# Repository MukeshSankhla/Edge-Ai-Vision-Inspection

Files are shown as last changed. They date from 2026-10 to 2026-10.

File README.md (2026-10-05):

# Edge AI Vision Inspection System
### Automated Optical Inspection (AOI) for Battery Management System (BMS) PCB & PCBA Manufacturing

An industrial-grade, multi-stage Automated Optical Inspection (AOI) platform engineered for electronics manufacturing lines. The system automates quality control on a 6-slot indexing rotary turntable, executing real-time defect detection, assembly verification, and bare PCB surface inspection using edge-optimized AI models.

Designed for edge deployment on the **Arduino UNO Q (Qualcomm QRB2210 Linux MPU + STM32U585 Zephyr MCU)** as well as standard Linux AArch64 / x86 SBCs and Windows workstations.

> 📖 **Project Story & Step-by-Step Build Tutorial:**
> Looking for the complete build walkthrough, 3D printing guide, Edge Impulse BYOM workflow, and step-by-step setup? Read the **[Project Guide & Build Tutorial](file:///c:/Users/MAKERBRAINS/Downloads/Edge%20Ai%20Vision%20Inspection/PROJECT_GUIDE.md)**!

---

## 📑 Table of Contents

- [System Overview](#-system-overview)
- [Repository Structure](#-repository-structure)
- [End-to-End Inspection Pipeline](#-end-to-end-inspection-pipeline)
- [Deep Learning Models](#-deep-learning-models)
  - [1. Slot Occupancy Detection](#1-stage-1-slot-occupancy-detection)
  - [2. Bare PCB Defect Inspection](#2-stage-2-bare-pcb-defect-inspection)
  - [3. Big Components Inspection](#3-stage-3a-big-components-inspection)
  - [4. Small Components Inspection](#4-stage-3b-small-components-inspection)
- [Hardware Architecture & Rotary Table](#-hardware-architecture--rotary-table)
- [Production Runtime (BMS EIM Vision Inspection)](#-production-runtime-bms-eim-vision-inspection)
- [Model Training & Conversion Workflow](#-model-training--conversion-workflow)
- [Installation & Quickstart](#-installation--quickstart)
  - [Prerequisites](#prerequisites)
  - [Running on Host PC (Windows / Linux)](#running-on-host-pc-windows--linux)
  - [Running on Arduino UNO Q (Linux SBC)](#running-on-arduino-uno-q-linux-sbc)
- [Web Dashboard Features](#-web-dashboard-features)
- [License & Credits](#-license--credits)

---

## 🔭 System Overview

```
                      ┌──────────────────────────────────────────────┐
                      │             Industrial Camera / USB          │
                      └──────────────────────┬───────────────────────┘
                                             │ Video Stream (RGB)
                                             ▼
┌────────────────────────────────────────────────────────────────────────────────────────┐
│                        Edge Processing Unit (Arduino UNO Q / Host PC)                  │
│                                                                                        │
│   ┌────────────────────────────────────────────────────────────────────────────────┐   │
│   │                      Flask Web Dashboard & AOI Controller                      │   │
│   └──────┬──────────────────────────────────────────────────────────────────┬──────┘   │
│          │                                                                  │          │
│          ▼ Image Frames                                                     ▼ Commands │
│   ┌─────────────────────────────────────────┐               ┌──────────────────────┐   │
│   │   Pure Native .EIM Model Inference Engine│              │  Hardware Interface  │   │
│   │   (ARM NEON SIMD / Shared Memory IPC)   │              │  (Bridge RPC / UART) │   │
│   │                                         │              └──────────┬───────────┘   │
│   │   1. Slot Occupancy (Empty/PCB/PCBA)    │                         │               │
│   │   2. Bare PCB Defects (Scratches/Bridges│                         │               │
│   │   3. Big Components (6 Parts - 12 Cls)  │                         │               │
│   │   4. Small Passives (13 Parts - 26 Cls) │                         │               │
│   └─────────────────────────────────────────┘                         │               │
└───────────────────────────────────────────────────────────────────────┼────────────────┘
                                                                        │
                                   ┌────────────────────────────────────┴────────────────┐
                                   │ STM32U585 MCU / Arduino Microcontroller Firmware    │
                                   └──────────────┬──────────────────────────┬───────────┘
                                                  │ PWM Pulse Stream         │ Single-Wire Data
                                                  ▼                          ▼
                                      ┌──────────────────────┐   ┌──────────────────────┐
                                      │ 6-Slot Rotary Table  │   │ WS2812B NeoPixel LED │
                                      │   (Servo Actuator)   │   │  (PASS/FAIL/STATUS)  │
                                      └──────────────────────┘   └──────────────────────┘
```

The system inspects printed circuit boards at each step of the manufacturing lifecycle:
1. **Verifies fixture occupancy** before initiating camera capture.
2. **Routes bare boards** to surface defect verification (solder bridges, scratches, copper oxidation, breaks).
3. **Routes assembled boards** to dual-model component verification, confirming both large functional units and miniature SMD passive elements are soldered correctly and none are missing.
4. **Physically indexes the turntable** through 6 inspection slots and drives visual pass/fail feedback LEDs synchronously.

---

## 📂 Repository Structure

The repository is modularly organized into training pipelines, edge runtime, and microcontroller firmware:

```
Edge Ai Vision Inspection/
├── BMS EIM Vision Inspection/          # Production Runtime & Operator Dashboard
│   ├── arduino_firmware/               # Microcontroller firmware for rotary & LED control
│   │   └── bms_servo_led/
│   │       ├── bms_servo_led.ino       # Non-blocking PWM & WS2812B controller sketch
│   │       └── README.md               # Detailed firmware documentation & hardware guide
│   ├── models/                         # Standalone compiled Edge Impulse (.eim) binaries
│   │   ├── slot-occupancy.eim          # Stage 1: Empty / PCB / PCBA classifier
│   │   ├── pcb-inspection.eim          # Stage 2: Bare PCB defect detection
│   │   ├── big-components-inspection.eim # Stage 3A: Large IC & connector verification
│   │   └── small-components-inspection.eim # Stage 3B: SMD passives verification
│   ├── snapshots/                      # Auto-saved defect and inspection image captures
│   ├── bms_eim_vision_inspection.py    # Main Flask server, camera pipeline, EIM runner
│   ├── requirements.txt                # Lightweight Python dependencies (no ONNX runtime)
│   ├── run_app.bat                     # Windows one-click launcher
│   ├── run_app.sh                      # Linux / Arduino UNO Q launcher
│   └── README.md                       # EIM deployment-specific guide
│
├── Slot Occuppancy Detection/          # Stage 1 Dataset & Model Training
│   ├── dataset/                        # Image data classified into Empty, PCB, PCBA
│   ├── labels_makesense_classification.csv # Raw annotations
│   ├── webcam_inspect.py               # Live camera testing script
│   └── TRAINING_STEPS.md               # Step-by-step training documentation
│
├── PCB Inspection/                     # Stage 2 Dataset & Model Training
│   ├── yolo_dataset/                   # Train/val/test splits with defect annotations
│   ├── data.yaml                       # YOLO dataset descriptor
│   ├── labels_makesense.csv            # Defect bounding boxes
│   ├── webcam_inspect.py               # Live camera testing script
│   └── TRAINING_STEPS.md               # Defect model training documentation
│
├── Big Components Inspection/          # Stage 3A Dataset & Model Training
│   ├── dataset/                        # Raw labeled images
│   ├── yolo_dataset/                   # Normalized YOLO bounding boxes
│   ├── train.py                        # YOLO training pipeline
│   ├── export_onnx.py                  # ONNX export script
│   ├── generate_representative_features.py # Quantization feature extractor
│   ├── predict.py / webcam_inspect.py  # Model validation & live camera inspection
│   └── TRAINING_STEPS.md               # Comprehensive YOLO training documentation
│
└── Small Componets Inspection/         # Stage 3B Dataset & Model Training
    ├── dataset/                        # Raw images with SMD passives
    ├── yolo_dataset/                   # Train/val splits with 26 classes
    ├── data.yaml                       # YOLO dataset descriptor
    ├── labels_makesense.csv            # Passive component bounding boxes
    ├── webcam_inspect.py               # Live camera testing script
    └── TRAINING_STEPS.md               # SMD passive model training documentation
```

---

## 🔄 End-to-End Inspection Pipeline

```mermaid
flowchart TD
    A[Start Inspection Cycle] --> B[Rotate Table to Target Slot 1..6]
    B --> C[Distance-Aware Adaptive Settle Delay]
    C --> D[Capture High-Res Frame]
    D --> E[Stage 1: Slot Occupancy EIM]
    
    E -->|Empty Slot| F[Set LED: Amber / Standby]
    F --> G[Log: Slot Empty - Skip Inspection]
    
    E -->|Bare PCB| H[Stage 2: Bare PCB Defect EIM]
    H --> I{Defects Detected?}
    I -->|0 Issues| J[PCB Clean: PASS]
    I -->|>=1 Issue| K[PCB Defective: FAIL]
    
    E -->|PCBA Board| L[Stage 3: Parallel PCBA Inspection]
    L --> M1[Stage 3A: Big Components EIM]
    L --> M2[Stage 3B: Small Passives EIM]
    M1 --> N[Merge Component Detections]
    M2 --> N
    
    N --> O{All Components Present?}
    O -->|All Present 'A'| P[PCBA Assembly: PASS]
    O -->|Any Missing 'N'| Q[PCBA Assembly: FAIL]
    
    J --> R[Hardware Feedback & Telemetry]
    K --> R
    P --> R
    Q --> R
    
    R --> S[Set WS2812B LED: Green PASS / Red FAIL]
    S --> T[Update Dashboard UI & Save Defect Snapshot]
    T --> U{Auto Mode Active?}
    U -->|Yes| V[Advance to Next Slot]
    V --> B
    U -->|No| W[Wait for Operator Command]
```

---

## 🧠 Deep Learning Models

### 1. Stage 1: Slot Occupancy Detection
- **Model File:** `slot-occupancy.eim`
- **Inference Task:** Image Classification
- **Classes:** `Empty`, `PCB`, `PCBA`
- **Logic:**
  - `Empty`: Skips component analysis; keeps conveyor/turntable moving or warns operator.
  - `PCB`: Automatically branches execution to bare-board defect inspection.
  - `PCBA`: Automatically branches execution to component placement verification.

### 2. Stage 2: Bare PCB Defect Inspection
- **Model File:** `pcb-inspection.eim`
- **Inference Task:** Object Detection
- **Classes:** `Issue` (scratch, solder bridge, open circuit, oxidation, trace defect)
- **Quality Rule:**
  $$\text{Defect Count} = 0 \implies \mathbf{PASS} \quad \Big| \quad \text{Defect Count} \ge 1 \implies \mathbf{FAIL}$$

### 3. Stage 3A: Big Components Inspection
- **Model File:** `big-components-inspection.eim`
- **Inference Task:** Object Detection
- **Classes (12):** `C1A`, `C1N`, `C2A`, `C2N`, `IA`, `IN`, `PA`, `PN`, `SA`, `SN`, `UA`, `UN`
- **Physical Components Checked:**
  - `S` : Main Switch / Mode Selector Socket (Top-Left)
  - `U` : Primary Controller IC / USB-C Interface (Top-Right)
  - `C1`: Bulk Electrolytic Capacitor 1 (Bottom-Left)
  - `I` : High-Current Power Inductor (Bottom Center-Left)
  - `P` : Battery Output Terminal / Power Port (Bottom Center-Right)
  - `C2`: Bulk Electrolytic Capacitor 2 (Bottom-Right)
- **Evaluation:** Evaluated as `A` (Available / Present) vs `N` (Absent / Missing). Any detected missing component (`*N`) or unverified component flags an immediate unit failure.

### 4. Stage 3B: Small Components Inspection
- **Model File:** `small-components-inspection.eim`
- **Inference Task:** Object Detection
- **Classes (26):**
  - **Capacitors (14 classes):** `C1A`, `C1N`, `C2A`, `C2N`, `C3A`, `C3N`, `C4A`, `C4N`, `C5A`, `C5N`, `C6A`, `C6N`, `C7A`, `C7N`
  - **Inductors / LEDs (4 classes):** `L1A`, `L1N`, `L2A`, `L2N`
  - **Resistors (8 classes):** `R1A`, `R1N`, `R3A`, `R3N`, `R4A`, `R4N`, `R5A`, `R5N`
- **Evaluation:** 13 physical component locations evaluated simultaneously. Guarantees 100% placement coverage for minute surface-mount passives.

---

## ⚙️ Hardware Architecture & Rotary Table

The physical workstation consists of a 6-position circular turntable driven by a heavy-duty servo motor and an overhead camera.

### Microcontroller Pin Assignments:

| Signal / Function | Microcontroller Pin | Destination / Component |
| :--- | :---: | :--- |
| **Servo PWM Signal** | **Pin 9** | Servo motor control line |
| **WS2812B NeoPixel Data** | **Pin 8** | Single-wire RGB indicator LED |
| **Logic Ground** | **GND** | Shared common ground |
| **5V Power** | **5V / External** | Dedicated 5V 2A power rail |

### Turntable Slot Position Calibration:

| Slot Number | Physical Angle | PWM Pulse Width | Target Description |
| :---: | :---: | :---: | :--- |
| **Slot 1** | $0^\circ$ | `480 - 500 µs` | Indexing Station / Home |
| **Slot 2** | $60^\circ$ | `930 - 940 µs` | Test Station 2 |
| **Slot 3** | $120^\circ$ | `1360 µs` | Test Station 3 |
| **Slot 4** | $180^\circ$ | `1780 - 1790 µs` | Test Station 4 |
| **Slot 5** | $240^\circ$ | `2220 µs` | Test Station 5 |
| **Slot 6** | $300^\circ$ | `2650 µs` | Test Station 6 |

### Anti-Blur Adaptive Settling Mechanism
Rotary turntables have rotational inertia. Capturing an image before the turntable has fully settled causes motion blur, degrading classification accuracy. 

The firmware implements **distance-aware adaptive pulse settling**:
- 1-slot step ($60^\circ$): Emits 45 pulses ($\sim 900\text{ ms}$).
- 5-slot full return (Slot 6 $\to$ Slot 1, $300^\circ$ reverse sweep): Emits 102 pulses ($\sim 2040\text{ ms}$).
- Python AOI orchestrator sleeps proportionally before triggering camera acquisition.

---

## ⚡ Production Runtime (BMS EIM Vision Inspection)

The deployment application in [`BMS EIM Vision Inspection`](file:///c:/Users/MAKERBRAINS/Downloads/Edge%20Ai%20Vision%20Inspection/BMS%20EIM%20Vision%20Inspection) features a zero-dependency architecture:

1. **Zero ONNX Runtime Dependency**:
   - Compiles models directly into standalone `.eim` ELF executables via Edge Impulse.
   - Saves hundreds of megabytes of memory and avoids fragile C++ runtime library incompatibilities on embedded Linux.
2. **Hardware SIMD Acceleration**:
   - Executes with native ARM NEON SIMD vector extensions on the QRB2210 Cortex-A53 cores.
3. **Aspect-Ratio Preserving Letterboxing ("Fit-Longest")**:
   - Scales the longest axis to model input dimensions and pads with zeros (`pad=0`), avoiding distortion so tiny SMD pads retain their true geometry.
4. **POSIX Shared Memory IPC**:
   - High-throughput zero-copy image transfer between Python and compiled `.eim` child processes using `multiprocessing.shared_memory`.
5. **Universal Hardware Communication**:
   - **Arduino UNO Q**: Connects natively over `/var/run/arduino-router.sock` MessagePack-RPC bridge.
   - **Serial UART**: Automatic fallback to USB-Serial at 115200 baud on standard Linux/Windows PCs.
   - **Virtual Simulator**: Built-in mock hardware layer for off-line UI and model testing without physical motors attached.

---

## 🛠️ Model Training & Conversion Workflow

Each inspection module (`Big Components Inspection`, `Small Componets Inspection`, `PCB Inspection`, `Slot Occuppancy Detection`) follows a structured pipeline:

```
[Raw Photos / Video Capture]
            │
            ▼
[MakeSense.ai Labeling] ──> Export annotations as CSV / YOLO TXT
            │
            ▼
[Dataset Conversion] ──> convert_makesense_to_yolo.py (Standardizes to YOLOv8/YOLO11 format)
            │
            ▼
[Dataset Integrity Check] ──> verify_dataset.py (Validates bounding box coordinates)
            │
            ▼
[Model Training] ──> train.py (YOLO11n / YOLOv8n object detection or classification)
            │
            ▼
[Validation & Verification] ──> predict.py / webcam_inspect.py
            │
            ▼
[Edge Impulse Ingestion] ──> Upload images & labels to Edge Impulse Studio
            │
            ▼
[Compile .EIM Executable] ──> Export as Linux ARM64 (AArch64) or x86_64 .eim binary
            │
            ▼
[Deploy to BMS EIM Runtime] ──> Place in 'BMS EIM Vision Inspection/models/'
```

---

## 🚀 Installation & Quickstart

### Prerequisites
- Python 3.10 - 3.12 (Recommended)
- USB Webcam or MIPI CSI Camera
- Arduino UNO Q or any standard Arduino board (with [`bms_servo_led.ino`](file:///c:/Users/MAKERBRAINS/Downloads/Edge%20Ai%20Vision%20Inspection/BMS%20EIM%20Vision%20Inspection/arduino_firmware/bms_servo_led/bms_servo_led.ino) flashed)

### Running on Host PC (Windows / Linux)

1. Open a terminal and navigate to the inspection directory:
   ```bash
   cd "BMS EIM Vision Inspection"
   ```

2. Install Python dependencies:
   ```bash
   pip install -r requirements.txt
   ```

3. Launch the application:
   - On Windows: Double-click `run_app.bat` or run:
     ```cmd
     python bms_eim_vision_inspection.py --source 0 --port COM3
     ```
   - On Linux:
     ```bash
     python3 bms_eim_vision_inspection.py --source 0 --port /dev/ttyACM0
     ```

4. Open your web browser to:
   ```
   http://localhost:5000
   ```

### Running on Arduino UNO Q (Linux SBC)

1. Connect to the Arduino UNO Q via SSH or terminal:
   ```bash
   cd "BMS EIM Vision Inspection"
   chmod +x models/*.eim run_app.sh
   ```

2. Start the production service:
   ```bash
   ./run_app.sh
   ```
   *(The script activates the virtual environment, configures the camera, and establishes communication via the internal Arduino Router Bridge.)*

3. Access the dashboard from any device on the local network at:
   ```
   http://<uno-q-ip-address>:5000
   ```

---

## 🖥️ Web Dashboard Features

- **Real-Time Video Stream**: Live 30 FPS video feed with customizable bounding box overlays, labels, and confidence thresholds.
- **Stage Progression Panel**: Instant visual status for Slot Occupancy, Bare PCB Defects, Big Components, and Small Passives.
- **Interactive Turntable Controls**: Manual single-click slot positioning (Slots 1 to 6) or automated continuous inspection cycle.
- **Live Pass/Fail Metrics**: Real-time counters tracking Total Inspected, Units Passed, Units Failed, and Yield Percentage.
- **Defect Snapshot Gallery**: Automatically records high-resolution timestamped image snapshots whenever an inspection defect is detected.
- **Hardware Telemetry**: Displays real-time communication link status (Bridge RPC, Serial UART, or Virtual Simulation).

---

## 📖 Further Documentation

- **Microcontroller Firmware & Wiring**: Refer to [Arduino Firmware README](file:///c:/Users/MAKERBRAINS/Downloads/Edge%20Ai%20Vision%20Inspection/BMS%20EIM%20Vision%20Inspection/arduino_firmware/bms_servo_led/README.md) for pinouts, non-blocking PWM details, serial protocol commands, and Bridge RPC setup.
- **Training Documentation**: Refer to the respective `TRAINING_STEPS.md` files in each inspection subfolder for dataset preparation and hyperparameter details.

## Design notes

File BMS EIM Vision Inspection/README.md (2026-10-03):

# BMS Vision Inspection — Pure Edge Impulse (.EIM) AOI System

An industrial-grade, photo-level **Automated Optical Inspection (AOI)** system designed for Battery Management System (BMS) PCB/PCBA manufacturing quality control. 

Engineered specifically for the **Arduino UNO Q** (dual-domain architecture with Qualcomm QRB2210 Linux MPU + STM32U585 Zephyr MCU) and edge Linux SBCs, running **strictly on compiled Edge Impulse (`.eim`) binaries with zero ONNX Runtime dependency**.

---

## 📑 Table of Contents
1. [System Architecture Overview](#system-architecture-overview)
2. [How `bms_eim_vision_inspection.py` Works](#how-bms_eim_vision_inspectionpy-works)
   - [1. Pure Native .EIM Execution Engine](#1-pure-native-eim-execution-engine)
   - [2. Fit-Longest Aspect-Ratio Preserving Preprocessing](#2-fit-longest-aspect-ratio-preserving-preprocessing)
   - [3. Multi-Stage Conditional Vision Pipeline](#3-multi-stage-conditional-vision-pipeline)
   - [4. Dual-Domain Arduino Hardware Controller](#4-dual-domain-arduino-hardware-controller)
   - [5. Zero-Lag Camera Draining Worker](#5-zero-lag-camera-draining-worker)
   - [6. Orchestration & Operating Modes (Auto vs Manual)](#6-orchestration--operating-modes-auto-vs-manual)
   - [7. Modern Industrial Web Dashboard & REST API](#7-modern-industrial-web-dashboard--rest-api)
3. [Component Matrix & Model Taxonomy](#component-matrix--model-taxonomy)
4. [Hardware Wiring & Turntable Specifications](#hardware-wiring--turntable-specifications)
5. [Directory Layout](#directory-layout)
6. [Installation & Requirements](#installation--requirements)
7. [Running the Application](#running-the-application)
8. [REST API Reference](#rest-api-reference)
9. [Troubleshooting & Diagnostics](#troubleshooting--diagnostics)

---

## 🏛️ System Architecture Overview

```mermaid
flowchart TD
    subgraph Hardware_Domain ["Hardware Domain (Arduino UNO Q / Rotary Fixture)"]
        Cam["HD USB / V4L2 Camera (1280x720)"]
        Servo["Servo Motor (Pin 9) - 6-Slot Turntable"]
        LED["WS2812B NeoPixel (Pin 8) - PASS/FAIL Indicator"]
        ZephyrMCU["STM32U585 MCU (Zephyr OS)"]
    end

    subgraph IPC_Link ["IPC Communication Layer"]
        RouterSock["/var/run/arduino-router.sock (MessagePack-RPC)"]
        SerialFallback["Serial UART Fallback (/dev/tty* or COM Port @ 115200)"]
    end

    subgraph Core_Pipeline ["bms_eim_vision_inspection.py"]
        CamWorker["Camera Drain Worker Thread (Zero Queue Lag)"]
        Orchestrator["Orchestrator Thread (Auto Loop / 10s Idle Watchdog)"]
        HWController["ArduinoHardwareController & UnoQBridgeClient"]
        
        subgraph Vision_Engine ["EIMVisionInspector Engine"]
            M1["Stage 1: slot-occupancy.eim (Empty / PCB / PCBA)"]
            M2A["Stage 2A: big-components-inspection.eim (6 Locations, 12 Classes)"]
            M2B["Stage 2B: small-components-inspection.eim (13 Locations, 26 Classes)"]
            M3["Stage 3: pcb-inspection.eim (Bare PCB Defect / Issue)"]
            ThreadPool["ThreadPoolExecutor (Parallel Dual-EIM Execution)"]
        end
    end

    subgraph Web_UI ["Industrial Web Dashboard (Port 5000)"]
        FlaskServer["Flask HTTP & REST Engine"]
        Dashboard["Single-Page Responsive UI (HUD, KPIs, Turntable Controller)"]
    end

    Cam -->|Continuous Frames| CamWorker
    CamWorker -->|Fresh Copy| Orchestrator
    Orchestrator -->|Slot Index Command| HWController
    HWController --> RouterSock --> ZephyrMCU
    HWController -.-> SerialFallback --> ZephyrMCU
    ZephyrMCU --> Servo
    ZephyrMCU --> LED

    Orchestrator --> Vision_Engine
    M1 -->|PCBA| ThreadPool
    ThreadPool --> M2A
    ThreadPool --> M2B
    M1 -->|PCB| M3
    M1 -->|Empty| EmptyVerdict["EMPTY Alert"]

    Vision_Engine -->|Verdict: PASS / FAIL| Orchestrator
    Orchestrator -->|Set Indicator LED| HWController
    Orchestrator -->|Telemetry & Annotated Photos| FlaskServer
    FlaskServer --> Dashboard
```

---

## ⚙️ How `bms_eim_vision_inspection.py` Works

The script is structured into modular, decoupled subsystems that operate concurrently using Python threading, inter-process communication (IPC), and real-time computer vision.

### 1. Pure Native .EIM Execution Engine (`NativeEIMRunner`)
- **Zero ONNX Runtime**: Unlike standard inference scripts that require large runtimes like `onnxruntime` or `torch`, this script directly executes compiled Edge Impulse Linux executables (`.eim`).
- **Subprocess & Unix Domain Socket IPC**:
  - The script spawns each `.eim` binary as an independent child process (`subprocess.Popen([model_path, sock_path])`).
  - It opens a dedicated Unix domain socket (`runner.sock`) in a secure temporary folder and establishes full-duplex JSON IPC communication.
  - Upon initialization, the runner sends a `{"hello": 1}` handshake to acquire the model dimensions, input format, label lists, and channel count.
- **POSIX Shared Memory (Zero-Copy)**:
  - If POSIX shared memory is supported (`HAS_SHM=True`), the runner accesses the model's shared memory segment (`features_shm`) via `multiprocessing.shared_memory`.
  - Tensors are written directly into shared memory without socket serialisation overhead, achieving ultra-low inference latency on ARM Cortex-A53 cores.
- **Cross-Platform Host Simulation**:
  - When executed on non-Linux operating systems (e.g., Windows or macOS during development), `NativeEIMRunner` detects that ELF AArch64 binaries cannot run natively and seamlessly shifts into simulation mode (`is_mock=True`). This allows full testing of the web interface, camera pipeline, and UI without crashing.

---

### 2. Fit-Longest Aspect-Ratio Preserving Preprocessing (`resize_fit_longest`)
Peripheral SMD components and edge solder joints are prone to being cut off if images are stretched or center-cropped:
- **Uniform Scaling**: The image is uniformly scaled based on `scale = min(target_w / orig_w, target_h / orig_h)` so the longest axis fits the model input (e.g., 640×640) without any geometric distortion.
- **Symmetric Zero-Padding**: The remaining borders are padded symmetrically with black pixels (`value=[0, 0, 0]`), matching the exact *fit-longest* DSP pipeline configured during Edge Impulse model training.
- **Vectorized Pixel Packing**: For unquantized float32 Edge Impulse models, pixels are packed into 32-bit unsigned integers `((R << 16) | (G << 8) | B)` using high-performance NumPy vectorization.
- **Coordinate Unprojection**: After the `.eim` binary returns bounding boxes relative to the letterboxed canvas, `_run_detection_runner()` mathematically unprojects each bounding box `(bx, by, bw, bh)` back to the original full-resolution camera coordinate space:
  $$\text{x}_1 = \frac{\text{bx} - \text{left\_pad}}{\text{scale}}, \quad \text{y}_1 = \frac{\text{by} - \text{top\_pad}}{\text{scale}}$$

---

### 3. Multi-Stage Conditional Vision Pipeline (`EIMVisionInspector`)

Inspection proceeds through an intelligent decision tree:

```
[ Captured Frame (1280x720) ]
              │
              ▼
   [ Stage 1: slot-occupancy.eim ]
              │
     ┌────────┼────────┐
     │        │        │
  "Empty"   "PCB"    "PCBA"
     │        │        │
     │        │        ▼
     │        │   [ Parallel PCBA Inspection ]
     │        │   ├─ Stage 2A: big-components-inspection.eim (6 Major ICs/Passives)
     │        │   └─ Stage 2B: small-components-inspection.eim (13 SMD Passives & LEDs)
     │        │        │
     │        │        ▼
     │        │   [ Component State Resolution ]
     │        │   (Verify all 19 components are PRESENT)
     │        │        │
     │        │   ┌────┴────┐
     │        │  PASS     FAIL
     │        │
     │        ▼
     │   [ Stage 3: pcb-inspection.eim ]
     │   (Bare PCB defect inspection: scratches, shorts, copper voids)
     │        │
     │   ┌────┴────┐
     │  PASS (0)  FAIL (≥1)
     ▼
[ Operator Alert / NeoPixel LED Update (GREEN = PASS, RED = FAIL) ]
```

#### Decision Stages:
1. **Stage 1 — Slot Occupancy (`slot-occupancy.eim`)**:
   - Classifies fixture contents into `Empty`, `PCB`, or `PCBA`.
   - If `Empty`, inspection stops immediately, logging an `EMPTY` status and setting the indicator to alert.
2. **Stage 2 — Assembled PCBA Inspection (Dual-Model Parallel)**:
   - When `PCBA` is detected, the pipeline spawns a concurrent thread pool (`ThreadPoolExecutor(max_workers=2)`).
   - Simultaneously runs `big-components-inspection.eim` (6 major components) and `small-components-inspection.eim` (13 miniature SMD components).
   - **Candidate Resolution**: For every physical designator, candidate bounding boxes are parsed. If both present (`A`) and missing (`N`) detections occur, the one with higher confidence is selected.
   - **Verdict Logic**:
     - **PASS**: All 19 components are detected as `PRESENT`.
     - **FAIL**: Any of the 19 components is detected as `MISSING`.
     - **PARTIAL SCAN**: If one or more components are unrecognized or occluded.
3. **Stage 3 — Bare PCB Defect Inspection (`pcb-inspection.eim`)**:
   - Triggered when Stage 1 determines the board is unpopulated (`PCB`).
   - Scans for manufacturing defects such as solder bridges, trace scratches, or surface issues.
   - **PASS**: 0 defects detected.
   - **FAIL**: $\ge 1$ defect detected.

---

### 4. Dual-Domain Arduino Hardware Controller (`ArduinoHardwareController`)

The hardware controller provides unified hardware control across multiple hardware configurations:

1. **Arduino UNO Q Direct Router Bridge (`UnoQBridgeClient`)**:
   - Communicates with the Linux-side router on the Arduino UNO Q via `/var/run/arduino-router.sock`.
   - Uses a pure Python standard-library implementation of **MessagePack-RPC notifications** (`_pack_notify`) to dispatch RPC commands directly to the STM32U585 MCU without third-party dependencies.
2. **Standard Serial UART Fallback**:
   - If running on a PC connected to a standard Arduino over USB or serial port (e.g., `COM3` or `/dev/ttyACM0`), it uses PySerial at 115200 baud.
   - Commands: `<slot_id>\n` to move servo, `P\n` for PASS (Green), `F\n` for FAIL (Red).
3. **Virtual Simulation Fallback**:
   - If no hardware is detected or if `--serial-port none` is passed, runs safely in simulation without throwing exceptions.
4. **Distance-Adaptive Travel & Motion-Blur Damping**:
   - Rotary table movement time adapts to the angular distance between slots:
     $$\text{travel\_time} = 
     \begin{cases} 
     0.40\,\text{s} & \text{if } \text{dist} = 0 \\ 
     0.82\,\text{s} & \text{if } \text{dist} = 1 \\ 
     0.82 + (\text{dist} - 1) \times 0.28\,\text{s} & \text{if } \text{dist} > 1 
     \end{cases}$$
   - Includes an additional **`0.22s` settling damping delay** after the servo arrives to ensure mechanical vibrations cease before capturing the photo.

---

### 5. Zero-Lag Camera Draining Worker (`_camera_worker`)
- Standard OpenCV `VideoCapture.read()` calls buffer frames in driver memory (V4L2 on Linux, DirectShow on Windows).
- A dedicated background thread continuously drains incoming frames at maximum camera frame rate into `self.latest_frame`.
- When an inspection occurs, `_capture_photo()` retrieves a fresh, unbuffered snapshot immediately after turntable stabilization, completely eliminating stale buffer frames.

---

### 6. Orchestration & Operating Modes (`_orchestrator_loop`)
- **AUTO Mode**: Automatically indexes through slots $1 \rightarrow 2 \rightarrow 3 \rightarrow 4 \rightarrow 5 \rightarrow 6$ sequentially, pauses for stabilization, runs the vision inspection, updates hardware LEDs, and waits 1.8 seconds before indexing the next nest.
- **MANUAL Mode**: Operators can click any slot (1–6) on the web dashboard to instantly index and inspect that specific nest.
- **10-Second Idle Watchdog (`AUTO_IDLE_TIMEOUT`)**: If the system remains in `MANUAL` mode without operator interaction for 10 seconds, the watchdog automatically returns the system to continuous `AUTO` loop mode.

---

### 7. Modern Industrial Web Dashboard & REST API
- Built-in Flask HTTP server serving a modern, responsive single-page dashboard.
- Live inspection viewport displaying 1280×720 annotated photos with color-coded bounding boxes (Green for Available, Red for Missing/Defects, Amber for warnings).
- Real-time KPIs: Cycle latency, slot occupancy classification, confidence rating, and surface state.
- Interactive turntable controls with live thumbnail history for each of the 6 slots.
- Hardware manual diagnostic controls to test individual servo positions (1–6) and toggle PASS/FAIL LEDs.
- Sensitivity threshold slider and center reticle ROI toggle.

---

## 🔍 Component Matrix & Model Taxonomy

### 1. Stage 1: Slot Occupancy (`slot-occupancy.eim`)
| Label | Description | Next Pipeline Action |
| :--- | :--- | :--- |
| `Empty` | Fixture nest is unoccupied | Log `EMPTY`, illuminate Amber/Red LED |
| `PCB` | Bare, unpopulated printed circuit board | Route to Stage 3 Bare PCB Defect Inspection |
| `PCBA` | Fully populated printed circuit board assembly | Route to Stage 2 Dual-Model PCBA Inspection |

### 2. Stage 2A: Major Components (`big-components-inspection.eim`)
Contains 12 trained classes across 6 critical physical locations:
| Component Key | Component Name | Available Label | Missing Label |
| :---: | :--- | :---: | :---: |
| **S** | Slide Switch / Socket | `SA` | `SN` |
| **U** | USB-C Receptacle / Main IC | `UA` | `UN` |
| **C1** | Large Bulk Capacitor 1 | `C1A` | `C1N` |
| **I** | Power Inductor | `IA` | `IN` |
| **P** | Power Management IC / Port | `PA` | `PN` |
| **C2** | Large Bulk Capacitor 2 | `C2A` | `C2N` |

### 3. Stage 2B: SMD Passives & LEDs (`small-components-inspection.eim`)
Contains 26 trained classes across 13 miniature component locations:
| Designator Group | Locations | Available Classes (`A`) | Missing Classes (`N`) |
| :--- | :--- | :--- | :--- |
| **SMD Capacitors** | C1, C2, C3, C4, C5, C6, C7 | `C1A` – `C7A` | `C1N` – `C7N` |
| **Inductors / LEDs** | L1, L2 | `L1A`, `L2A` | `L1N`, `L2N` |
| **SMD Resistors** | R1, R3, R4, R5 | `R1A`, `R3A`, `R4A`, `R5A` | `R1N`, `R3N`, `R4N`, `R5N` |

### 4. Stage 3: Bare PCB Defect Inspection (`pcb-inspection.eim`)
| Class | Evaluation Rule |
| :--- | :--- |
| `Issue` | **0 Detections** = `PASS` (Clean board surface)<br>**$\ge$ 1 Detection** = `FAIL` (Trace defect, scratch, bridge, or void) |

---

## 🔌 Hardware Wiring & Turntable Specifications

```
                     ┌───────────────────────────┐
                     │      ARDUINO UNO Q        │
                     │  (QRB2210 + STM32U585)    │
                     │                           │
                     │   [Pin 9] ─── PWM ───────►│─── Servo Motor Signal (Yellow/Orange)
                     │   [Pin 8] ─── DIN ───────►│─── WS2812B NeoPixel DIN (Green)
                     │   [5V]    ─── VCC ───────►│─── Logic Power
                     │   [GND]   ─── GND ───────►│─── Common Ground
                     └───────────────────────────┘
```

> [!IMPORTANT]
> When operating high-torque servos, power the servo motor via an **external dedicated 5V 2A power supply**, tying external GND to Arduino GND.

### Turntable Calibrated Servo Pulses
| Slot ID | Turntable Angle | Microseconds ($\mu\text{s}$) |
| :---: | :---: | :---: |
| **Slot 1** | 0° | `500 µs` |
| **Slot 2** | 60° | `930 µs` |
| **Slot 3** | 120° | `1360 µs` |
| **Slot 4** | 180° | `1790 µs` |
| **Slot 5** | 240° | `2220 µs` |
| **Slot 6** | 300° | `2650 µs` |

---

## 📂 Directory Layout

```
BMS EIM Vision Inspection/
├── bms_eim_vision_inspection.py   # Main inspection engine, hardware controller, and dashboard
├── requirements.txt               # Lightweight runtime dependencies (Flask, OpenCV, NumPy, PySerial)
├── README.md                      # Comprehensive technical documentation
├── arduino_logo.jpg               # Branding asset for web dashboard
├── ei_logo.png                    # Edge Impulse branding asset for web dashboard
├── models/                        # Compiled Edge Impulse .eim executables
│   ├── slot-occupancy.eim         # Stage 1: Fixture occupancy classification
│   ├── big-components-inspection.eim   # Stage 2A: 6 major components
│   ├── small-components-inspection.eim # Stage 2B: 13 miniature SMD components
│   └── pcb-inspection.eim         # Stage 3: Bare PCB surface defect detection
├── arduino_firmware/              # Arduino / Zephyr MCU firmware
│   └── bms_servo_led/
│       ├── bms_servo_led.ino      # Dual-mode sketch (Bridge RPC & Serial fallback)
│       └── README.md              # Firmware flashing & architecture guide
└── snapshots/                     # Cached captures and verification frames
```

---

## 📦 Installation & Requirements

### Dependencies
The runtime strictly avoids heavy deep learning frameworks:
```
flask>=2.2.0
opencv-python-headless>=4.5.1.48
numpy>=1.20.0
pyserial>=3.5
```

### Install in Virtual Environment:
```bash
# Create and activate virtual environment
python -m venv .venv

# On Linux:
source .venv/bin/activate

# On Windows:
.venv\Scripts\activate

# Install dependencies
pip install -r requirements.txt
```

> [!TIP]
> On headless Linux SBCs (e.g. Arduino UNO Q), install `opencv-python-headless` instead of `opencv-python` to eliminate unnecessary X11/GUI library dependencies.

---

## 🚀 Running the Application

### 1. On Arduino UNO Q (Linux MPU):
```bash
# Make models executable
chmod +x models/*.eim

# Launch with default camera (0) and automatic UNO Q Bridge connection
python3 bms_eim_vision_inspection.py --source 0 --serial-port bridge
```

### 2. On Host PC / Testing Machine:
```bash
# Run with local USB webcam and simulation or serial port:
python bms_eim_vision_inspection.py --source 0 --serial-port auto
```

### Command-Line Arguments:
| Argument | Type | Default | Description |
| :--- | :---: | :---: | :--- |
| `--source` | `str` | `"0"` | Camera index (`"0"`, `"1"`), video path (`.mp4`), or image path |
| `--serial-port`| `str` | `"auto"` | Hardware port (`"bridge"`, `"auto"`, `"/dev/ttyACM0"`, `"COM3"`, `"none"`) |
| `--baud` | `int` | `115200` | Baud rate for serial UART |
| `--port` | `int` | `5000` | HTTP port for web dashboard |
| `--host` | `str` | `"0.0.0.0"`| Host interface binding (`0.0.0.0` allows LAN access) |
| `--conf` | `float`| `0.20` | Detection confidence cutoff for PCBA components (0.10 to 0.90) |
| `--pcb-conf` | `float`| `0.60` | Defect confidence cutoff for bare PCB issues |
| `--use-roi` | `flag` | `True` | Restricts defect analysis to center reticle area |
| `--full-frame` | `flag` | — | Disables reticle filtering and inspects full field-of-view |

Open your web browser and navigate to:
```
http://localhost:5000
```
*(Or `http://<device-ip>:5000` from any device on your local network).*

---

## 🌐 REST API Reference

The embedded Flask server exposes real-time endpoints for machine-to-machine integration and factory automation:

| Endpoint | Method | Description | Payload / Response |
| :--- | :---: | :--- | :--- |
| `/` | `GET` | Serves the web dashboard single-page interface | HTML |
| `/api/status` | `GET` | Current system telemetry, active slot, and all slot statuses | JSON |
| `/api/slot_photo/<int:slot_id>` | `GET` | Fetches the latest annotated JPEG photo for a specific slot | `image/jpeg` |
| `/api/select_slot/<int:slot_id>` | `POST` | Manually commands turntable to index and inspect a slot | `{"success": true, "slot": {...}}` |
| `/api/toggle_mode` | `POST` | Toggles between `AUTO` loop and `MANUAL` mode | `{"success": true, "mode": "AUTO"}` |
| `/api/hardware/ports` | `GET` | Scans and lists all available serial and bridge ports | `{"ports": [...]}` |
| `/api/hardware/connect` | `POST` | Connects or reconnects to a specified port | `{"port": "COM3", "baud": 115200}` |
| `/api/hardware/test_servo/<int:slot_id>` | `POST` | Diagnostic command to pulse servo to slot position | `{"success": true, "slot": 2}` |
| `/api/hardware/test_led/<color>` | `POST` | Diagnostic command to set NeoPixel LED (`PASS` or `FAIL`) | `{"success": true, "color": "PASS"}` |
| `/api/config/sensitivity` | `POST` | Updates AI confidence cutoff and reticle ROI filtering | `{"conf": 0.25, "use_roi": true}` |

---

## 🛠️ Troubleshooting & Diagnostics

- **OpenCV VideoCapture missing**:
  - If you encounter errors mentioning `has no VideoCapture`, an empty dummy package named `cv2` was installed from PyPI. Fix by running:
    ```bash
    pip uninstall -y cv2 opencv-python opencv-python-headless
    pip install --no-cache-dir opencv-python-headless
    ```
- **Permission denied executing `.eim`**:
  - Run `chmod +x models/*.eim` to grant execution permissions to the binaries on Linux.
- **Turntable jitter or brownout**:
  - Servos drawing sudden inrush current can drop the 5V rail on small SBCs. Ensure the servo is supplied by an external 5V 2A DC supply with shared ground.
- **Motion blur during image capture**:
  - The script enforces an adaptive travel delay and a `0.22s` settling damping pause. If your turntable has significant mass, adjust the settle pause in `inspect_slot()` or tune mechanical damping.

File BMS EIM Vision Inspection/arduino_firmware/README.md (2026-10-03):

# Arduino Firmware Directory

This folder contains the embedded microcontroller firmware driving the physical automation hardware for the BMS Automated Optical Inspection (AOI) system.

## Subdirectories

- **[`bms_servo_led/`](file:///c:/Users/MAKERBRAINS/Downloads/Edge%20Ai%20Vision%20Inspection/BMS%20EIM%20Vision%20Inspection/arduino_firmware/bms_servo_led)**: Complete Arduino sketch (`bms_servo_led.ino`) and documentation.
  - Controls the 6-slot rotary inspection turntable via distance-aware non-blocking PWM (Pin 9).
  - Drives the WS2812B NeoPixel RGB indicator (Pin 8) with PASS/FAIL/MOVING/STANDBY colors.
  - Supports dual operation on Arduino UNO Q (Router Bridge RPC) and standard Arduino boards (Serial UART @ 115200 baud).

For complete hardware pinouts, protocol commands, timing diagrams, and flashing instructions, refer to **[`bms_servo_led/README.md`](file:///c:/Users/MAKERBRAINS/Downloads/Edge%20Ai%20Vision%20Inspection/BMS%20EIM%20Vision%20Inspection/arduino_firmware/bms_servo_led/README.md)**.

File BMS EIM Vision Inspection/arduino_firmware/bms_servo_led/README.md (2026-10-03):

# BMS Vision Inspection — Rotary Table Servo & WS2812B Controller Firmware

Firmware for the 6-slot indexing rotary turntable and WS2812B RGB NeoPixel inspection indicator in the BMS Automated Optical Inspection (AOI) system.

Compatible with:
- **Arduino UNO Q** (Qualcomm QRB2210 Linux MPU + STM32U585 Zephyr MCU via internal MessagePack Bridge RPC)
- **Standard Arduino & Microcontroller Boards** (UNO R3/R4, Nano, Mega, ESP32, RP2040, STM32 via USB-Serial UART @ 115200 baud)

---

## 📑 Table of Contents

- [Overview & Key Features](#-overview--key-features)
- [Hardware Wiring & Pinout](#-hardware-wiring--pinout)
- [How the Code Works](#-how-the-code-works)
  - [1. Dual-Architecture Communication](#1-dual-architecture-communication)
  - [2. Non-Blocking 50 Hz Software Pulse Generator](#2-non-blocking-50-hz-software-pulse-generator)
  - [3. Distance-Aware Adaptive Settle Engine](#3-distance-aware-adaptive-settle-engine)
  - [4. Calibrated Slot Microsecond Pulse Table](#4-calibrated-slot-microsecond-pulse-table)
  - [5. WS2812B LED Color Indications](#5-ws2812b-led-color-indications)
- [Serial UART Protocol Specification](#-serial-uart-protocol-specification)
- [Arduino UNO Q Bridge RPC Specification](#-arduino-uno-q-bridge-rpc-specification)
- [Dependencies & Installation](#-dependencies--installation)
- [Compilation & Flashing](#-compilation--flashing)
  - [Option A: Arduino IDE](#option-a-arduino-ide)
  - [Option B: PlatformIO CLI](#option-b-platformio-cli)
  - [Option C: Arduino UNO Q App Lab / CLI](#option-c-arduino-uno-q-app-lab--cli)
- [Testing & Verification](#-testing--verification)

---

## 🎯 Overview & Key Features

The `bms_servo_led.ino` sketch acts as the low-latency hardware actuator bridge between the high-level Python AOI vision inspection engine and the physical inspection rig.

### Key Capabilities:
- **Non-Blocking Control Loop:** Does not rely on blocking `delay()` calls or traditional hardware timers that conflict with the NeoPixel library or Zephyr RTOS scheduler.
- **Distance-Aware Settling:** Rotary indexing mechanisms have angular inertia. The firmware dynamically emits calibrated stabilization pulse bursts based on distance traveled, completely eliminating camera motion blur.
- **Dual Communication Modes:** Seamlessly services high-speed MessagePack Bridge RPC on the Arduino UNO Q while concurrently serving an ASCII command protocol over hardware Serial UART.
- **Visual Status Annunciation:** Drives an ultra-bright WS2812B addressable LED with dedicated colors for Moving, Pass, Fail, and Standby states.

---

## 🔌 Hardware Wiring & Pinout

```
   ┌────────────────────────────────────────────────────────┐
   │             Arduino / STM32 / UNO Q MCU                │
   │                                                        │
   │   [Pin 9] (PWM Out) ──────> Servo Motor Signal (Yellow)│
   │   [Pin 8] (GPIO Out)─────> WS2812B DIN (Data In)       │
   │   [GND]   ───────────────> Common Logic GND            │
   │   [5V]    ───────────────> Logic 5V VCC                │
   └────────────────────────────────────────────────────────┘
                                   │
                                   ▼
        ┌─────────────────────────────────────────────────┐
        │  *RECOMMENDED EXTERNAL POWER FOR SERVO MOTOR*   │
        │  - External 5V / 2A DC Power Supply             │
        │  - Servo +5V (Red) ──> External 5V (+)          │
        │  - Servo GND (Brown)─> External GND (-) & MCU G │
        └─────────────────────────────────────────────────┘
```

| MCU Pin | Signal Name | Connected Device | Function |
| :---: | :---: | :--- | :--- |
| **Pin 9** | `SERVO_PIN` | Rotary Servo Signal Wire (White/Yellow) | Software 50Hz PWM pulse train |
| **Pin 8** | `LED_PIN` | WS2812B NeoPixel Data In (`DIN`) | 800 kHz single-wire NeoPixel data |
| **GND** | `GND` | Servo GND + LED GND + Power Supply GND | Common electrical reference |
| **5V** | `5V` | LED VDD (+5V) | Power for single WS2812B LED |

> [!WARNING]
> High-torque servo motors can draw momentary peak currents up to 1.5A–2.0A during rapid rotary table index sweeps. **Always power the servo from an external regulated 5V power supply with a common ground**, rather than drawing power directly from the microcontroller's 5V regulator.

---

## 🧠 How the Code Works

### 1. Dual-Architecture Communication

The firmware uses conditional compilation to detect whether it is compiling for the Arduino UNO Q's Zephyr RTOS core:

```cpp
#if defined(ARDUINO_ARCH_ZEPHYR) || defined(ARDUINO_UNO_Q) || __has_include(<Arduino_RouterBridge.h>)
#include <Arduino_RouterBridge.h>
#define HAS_ROUTER_BRIDGE 1
#endif
```

- When running on **Arduino UNO Q**, it calls `Bridge.begin()` and registers two RPC callback methods:
  - `Bridge.provide_safe("move_servo", moveServoSlot);`
  - `Bridge.provide_safe("set_led", setLedState);`
  The `provide_safe` wrapper ensures calls from the Qualcomm QRB2210 Linux MPU execute safely across threads without interrupting critical MCU routines.
- Simultaneously, it initializes `Serial.begin(115200)`, allowing standard USB-Serial or UART monitoring and control on any Arduino platform.

---

### 2. Non-Blocking 50 Hz Software Pulse Generator

Standard Arduino `Servo.h` libraries frequently conflict with the strict timing interrupts required by the `Adafruit_NeoPixel` library (which turns off interrupts during `strip.show()`). Furthermore, on Zephyr-based RTOS boards like the Arduino UNO Q, hardware timer allocations differ.

To ensure 100% rock-solid determinism, `bms_servo_led.ino` generates RC servo PWM pulses manually using a non-blocking timestamp counter:

```cpp
unsigned long now = micros();

// Generate 50Hz PWM pulses non-blockingly (every 20,000 microseconds = 50 Hz)
if (pulsesRemaining > 0 && (now - lastPulseTime >= 20000)) {
  lastPulseTime = now;
  digitalWrite(SERVO_PIN, HIGH);
  delayMicroseconds(targetPulse);
  digitalWrite(SERVO_PIN, LOW);
  pulsesRemaining--;

  // Send completion notification ONLY when motor has completely finished all pulses!
  if (pulsesRemaining == 0) {
    Serial.print("OK:MOVED:");
    Serial.println(currentSlot);
  }
}
```

- **Period:** Exactly 20,000 µs (50 Hz frame rate).
- **Pulse Duration:** Held HIGH for `targetPulse` microseconds (between 480 µs and 2650 µs), then pulled LOW.
- **Zero Drift:** Uses `micros()` delta comparison, allowing `loop()` to continuously check serial commands or bridge notifications without stalling.

---

### 3. Distance-Aware Adaptive Settle Engine

A major engineering challenge with rotary inspection tables is mechanical inertia and settling vibration. When moving 1 slot ($60^\circ$), the table reaches destination quickly. However, when resetting from **Slot 6 back to Slot 1** ($300^\circ$ reverse sweep), the table carries high momentum. If the camera captures an image too soon, the resulting image is blurry.

The `moveServoSlot(int slot)` function dynamically adapts the number of pulses generated:

```cpp
void moveServoSlot(int slot) {
  if (slot >= 1 && slot <= 6) {
    int dist = abs(slot - currentSlot);
    currentSlot = slot;
    targetPulse = POSITIONS[slot - 1];

    if (dist <= 1) {
      pulsesRemaining = 45;              // 45 pulses * 20ms = ~900 ms
    } else {
      pulsesRemaining = 45 + (dist - 1) * 15; // e.g. dist 5: 105 pulses = ~2100 ms
    }
  }
}
```

| Travel Type | Slot Delta (`dist`) | Number of Pulses | Active Settling Duration | Mechanical Objective |
| :--- | :---: | :---: | :---: | :--- |
| **Stationary / Same Slot** | 0 | 45 | 900 ms | Holds position steady |
| **Adjacent Step** (e.g. 1 $\to$ 2) | 1 | 45 | 900 ms | Smooth indexing step |
| **2-Step Move** (e.g. 1 $\to$ 3) | 2 | 60 | 1,200 ms | Intermediate travel dampening |
| **3-Step Move** (e.g. 1 $\to$ 4) | 3 | 75 | 1,500 ms | Half-circle dampening |
| **4-Step Move** (e.g. 1 $\to$ 5) | 4 | 90 | 1,800 ms | Extended travel settling |
| **Full Reverse** (6 $\to$ 1) | 5 | 105 | 2,100 ms | Complete dampening of $300^\circ$ inertia sweep |

Only after the last pulse is delivered does the MCU emit `OK:MOVED:<slot>`, notifying the Python host that the table is dead still and ready for optical capture.

---

### 4. Calibrated Slot Microsecond Pulse Table

```cpp
const int POSITIONS[6] = {480, 940, 1360, 1780, 2220, 2650};
```

```
                     Slot 1 (480 µs / ~0°)
                            ▲
                            │
       Slot 6 (2650 µs) ────┼──── Slot 2 (940 µs)
                            │
       Slot 5 (2220 µs) ────┼──── Slot 3 (1360 µs)
                            │
                            ▼
                     Slot 4 (1780 µs / ~180°)
```

These pulse widths correspond to standard 180° / 270° / 300° wide-angle precision industrial servos. If your turntable mechanical linkage or gearing ratio requires different angles, adjust the `POSITIONS` array in line 49.

---

### 5. WS2812B LED Color Indications

The addressable NeoPixel LED delivers instantaneous feedback to human operators:

| LED Color | RGB Code | Constant | Inspection Context |
| :--- | :---: | :---: | :--- |
| **ORANGE** | `(255, 120, 0)` | `setOrange()` | Turntable in motion; position changing |
| **GREEN** | `(0, 255, 0)` | `setGreen()` | Inspection **PASS** (Zero defects detected) |
| **RED** | `(255, 0, 0)` | `setRed()` | Inspection **FAIL** (Defects or missing components) |
| **AMBER** | `(160, 90, 0)` | `setAmber()` | Standby / Empty fixture slot detected / Bootup |
| **OFF** | `(0, 0, 0)` | `setOff()` | Sleep / Diagnostic mode |

---

## 📡 Serial UART Protocol Specification

Baud Rate: **115200** | Data Bits: **8** | Parity: **None** | Stop Bits: **1**

### Commands (Host $\to$ MCU):

| Command (ASCII) | Description | Example |
| :---: | :--- | :---: |
| `'1'` – `'6'` | Move turntable to designated slot index | `2\n` |
| `'P'` / `'p'` | Set status LED to GREEN (PASS) | `P\n` |
| `'F'` / `'f'` | Set status LED to RED (FAIL) | `F\n` |
| `'O'` / `'o'` | Set status LED to ORANGE (Moving) | `O\n` |
| `'E'` / `'e'` | Set status LED to AMBER (Empty / Standby) | `E\n` |
| `'?'` | Query firmware readiness status | `?\n` |

### Responses (MCU $\to$ Host):

| Response (ASCII) | Trigger Condition | Meaning |
| :--- | :--- | :--- |
| `OK:READY` | Startup or in response to `'?'` ping | Firmware initialized and ready |
| `ACK:MOVE:<N>` | Immediately upon receiving `'1'`..`'6'` | Command accepted, motion began |
| `OK:MOVED:<N>` | When all adaptive pulses finish | Turntable has fully settled at slot `<N>` |
| `OK:PASS` | In response to `'P'` | LED set to Green |
| `OK:FAIL` | In response to `'F'` | LED set to Red |
| `OK:ORANGE` | In response to `'O'` | LED set to Orange |
| `OK:EMPTY` | In response to `'E'` | LED set to Amber |
| `ERR:UNKNOWN_CMD:<C>` | Any unrecognized character | Syntax error or unsupported command |

---

## ⚡ Arduino UNO Q Bridge RPC Specification

When compiled with `HAS_ROUTER_BRIDGE`, the sketch exports RPC endpoints to the internal UNIX domain socket router (`/var/run/arduino-router.sock`):

### 1. `move_servo(int slot)`
- **Parameters:** `slot` (Integer: `1` to `6`)
- **Execution:** Safe non-blocking execution (< 1 µs execution time). Updates `targetPulse` and starts the pulse generator state machine.
- **Python Invocation:**
  ```python
  bridge_client.notify("move_servo", 3)
  ```

### 2. `set_led(String col)`
- **Parameters:** `col` (String: `"PASS"`, `"FAIL"`, `"ORANGE"`, `"AMBER"`, `"GREEN"`, `"RED"`)
- **Execution:** Case-insensitive parser updates the WS2812B NeoPixel buffer immediately.
- **Python Invocation:**
  ```python
  bridge_client.notify("set_led", "PASS")
  ```

---

## 📦 Dependencies & Installation

### Required Arduino Libraries:
1. **Adafruit NeoPixel** (by Adafruit) — Install via Arduino IDE Library Manager or `pio pkg install -l "adafruit/Adafruit NeoPixel"`.
2. **Arduino_RouterBridge** (pre-installed in the Arduino UNO Q core board package; automatically included when targeting UNO Q).

---

## 🚀 Compilation & Flashing

### Option A: Arduino IDE
1. Open the Arduino IDE (v2.x recommended).
2. Open [`bms_servo_led.ino`](file:///c:/Users/MAKERBRAINS/Downloads/Edge%20Ai%20Vision%20Inspection/BMS%20EIM%20Vision%20Inspection/arduino_firmware/bms_servo_led/bms_servo_led.ino).
3. Install **Adafruit NeoPixel** from **Tools $\to$ Manage Libraries...**.
4. Select your board:
   - For standard Arduino: Select **Arduino Uno**, **Arduino Nano**, or corresponding board.
   - For Arduino UNO Q: Select **Arduino UNO Q (STM32U585)**.
5. Select the correct COM / Serial port.
6. Click **Upload** ($\rightarrow$).

### Option B: PlatformIO CLI
Create a minimal `platformio.ini` in the firmware folder:
```ini
[env:uno]
platform = atmelavr
board = uno
framework = arduino
lib_deps =
    adafruit/Adafruit NeoPixel@^1.12.0
monitor_speed = 115200
```
Then run:
```bash
pio run --target upload
```

### Option C: Arduino UNO Q App Lab / CLI
```bash
arduino-app-cli compile --fqbn arduino:zephyr:uno_q bms_servo_led
arduino-app-cli upload --fqbn arduino:zephyr:uno_q bms_servo_led
```

---

## 🧪 Testing & Verification

### Using Serial Monitor:
1. Open the Arduino IDE Serial Monitor (or PuTTY / minicom) at **115200 baud** with `Newline` (`\n`) line ending.
2. Observe startup output:
   ```
   OK:READY
   ```
3. Type `2` and press Enter:
   - Observe immediate reply: `ACK:MOVE:2`
   - The LED turns Orange during motion.
   - Servo rotates smoothly to Slot 2 position.
   - Upon settling ($\sim 900$ ms), observe completion message: `OK:MOVED:2`.
4. Type `P` and press Enter:
   - Observe reply: `OK:PASS`
   - LED instantly turns vivid Green.
5. Type `F` and press Enter:
   - Observe reply: `OK:FAIL`
   - LED instantly turns vivid Red.

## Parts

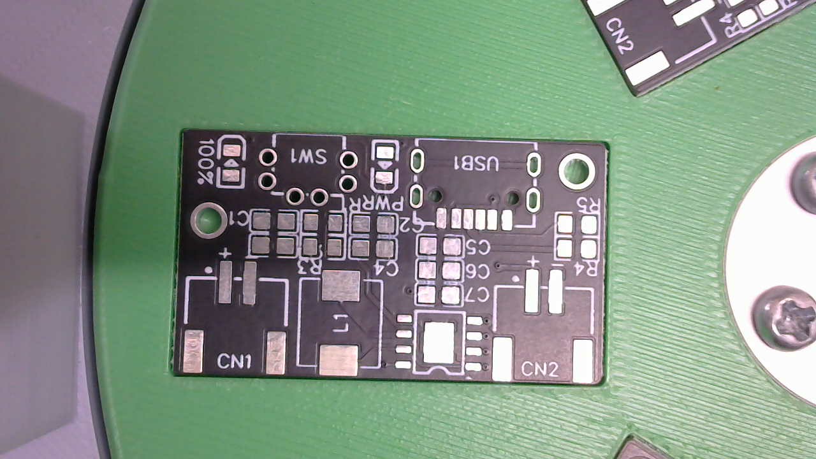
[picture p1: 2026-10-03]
Big Components Inspection/yolo_dataset/images/train/WIN_20260928_09_51_20_Pro.jpg

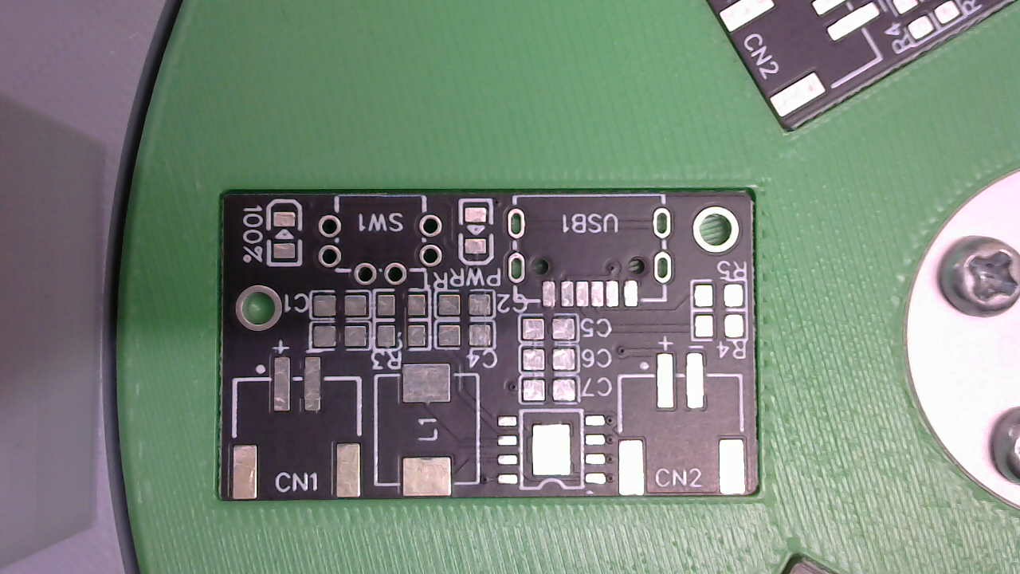
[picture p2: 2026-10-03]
Big Components Inspection/yolo_dataset/images/train/WIN_20260928_09_51_46_Pro.jpg

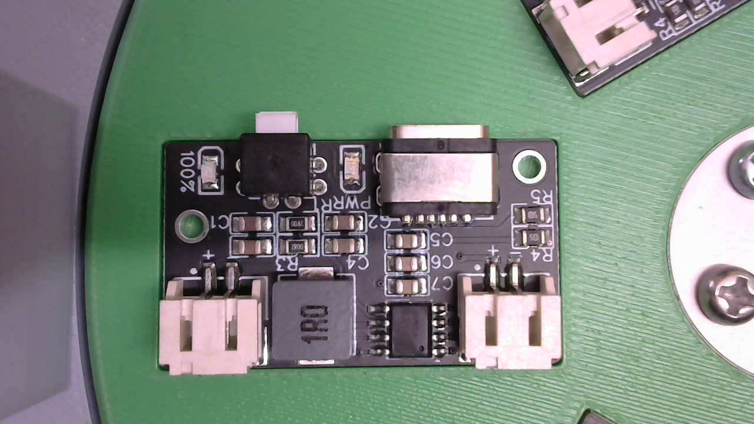
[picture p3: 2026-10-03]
Big Components Inspection/yolo_dataset/images/val/WIN_20260928_09_46_50_Pro.jpg

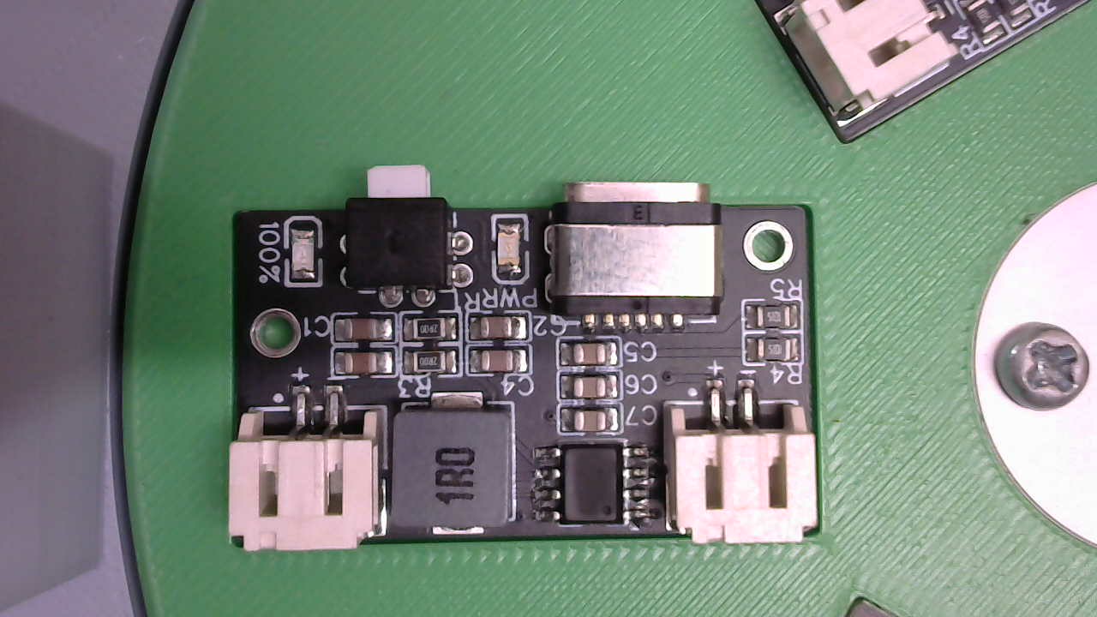
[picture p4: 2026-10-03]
Big Components Inspection/yolo_dataset/images/val/WIN_20260928_09_47_46_Pro.jpg

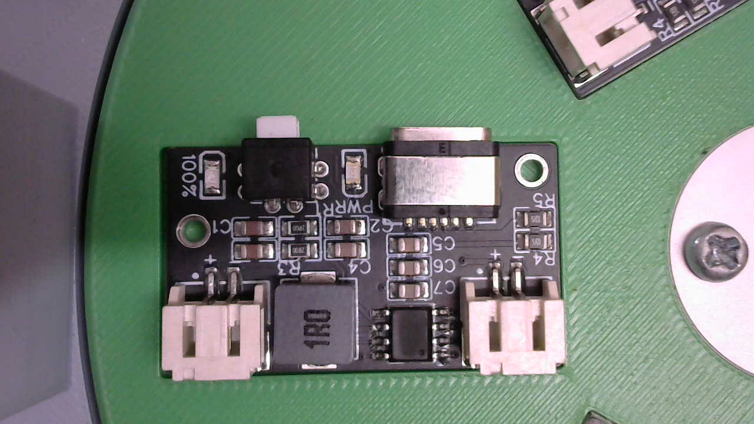
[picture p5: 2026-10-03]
Big Components Inspection/yolo_dataset/images/train/WIN_20260928_09_43_29_Pro.jpg

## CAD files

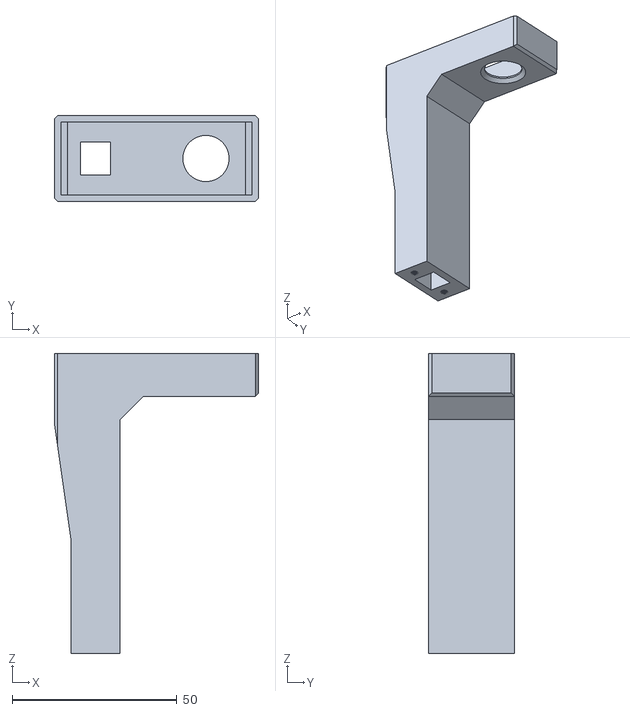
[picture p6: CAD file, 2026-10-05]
CAD/Pole.stl
62.0 x 26.0 x 91.0

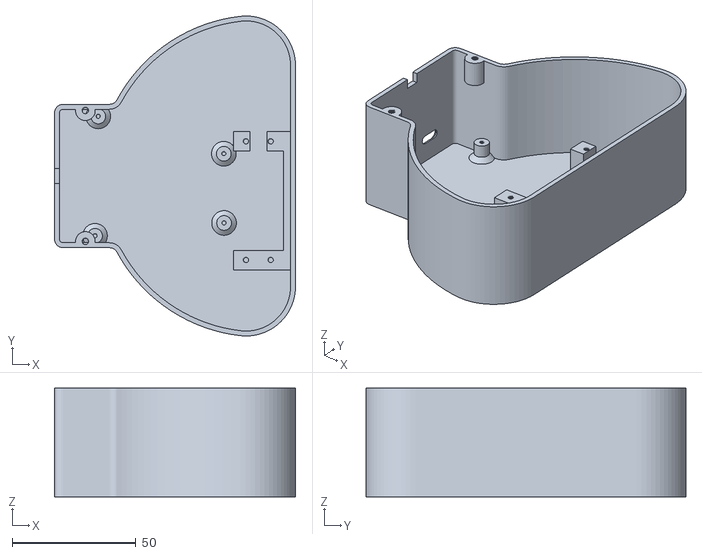
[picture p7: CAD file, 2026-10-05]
CAD/Body.stl
97.5 x 129.4 x 44.0

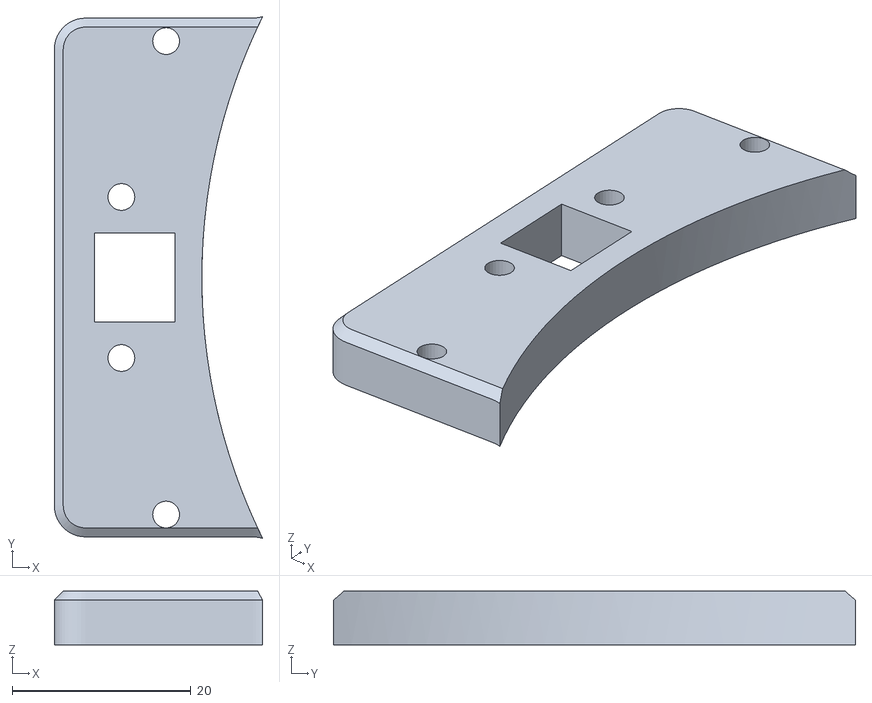
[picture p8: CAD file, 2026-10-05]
CAD/Mount.stl
23.3 x 58.4 x 6.00

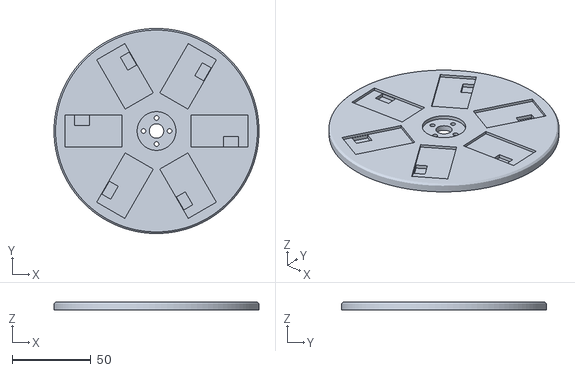
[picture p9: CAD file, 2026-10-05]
CAD/Plate.stl
130.0 x 130.0 x 5.00

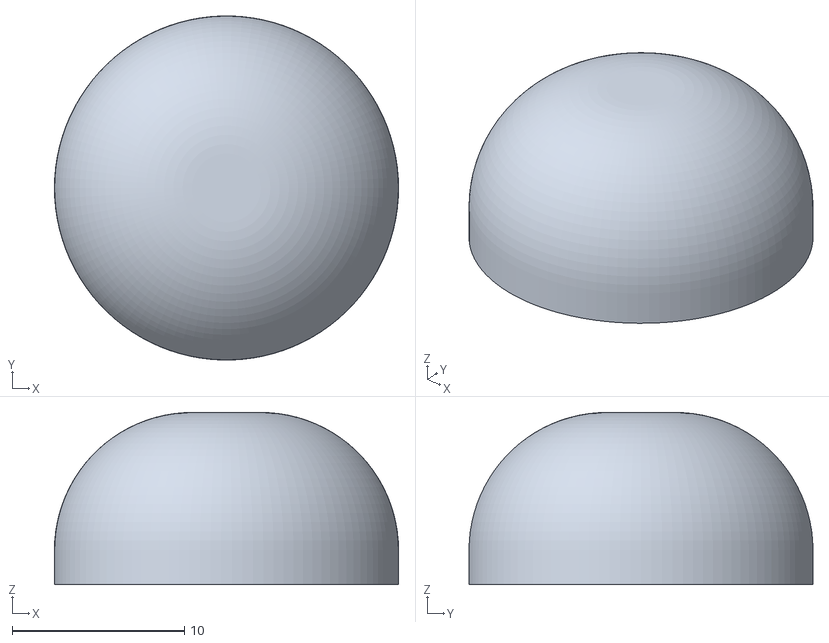
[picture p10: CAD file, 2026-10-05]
CAD/Diffuser.stl
20.0 x 20.0 x 10.0

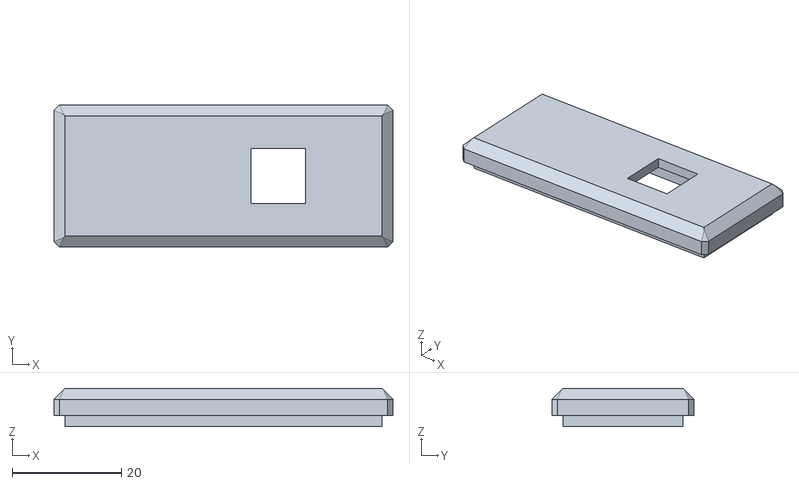
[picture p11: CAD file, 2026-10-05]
CAD/Cap.stl
62.0 x 26.0 x 7.00

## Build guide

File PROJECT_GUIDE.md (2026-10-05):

# Edge AI Vision Inspection System: Transforming a $60 SBC into an Industrial Inspection Station

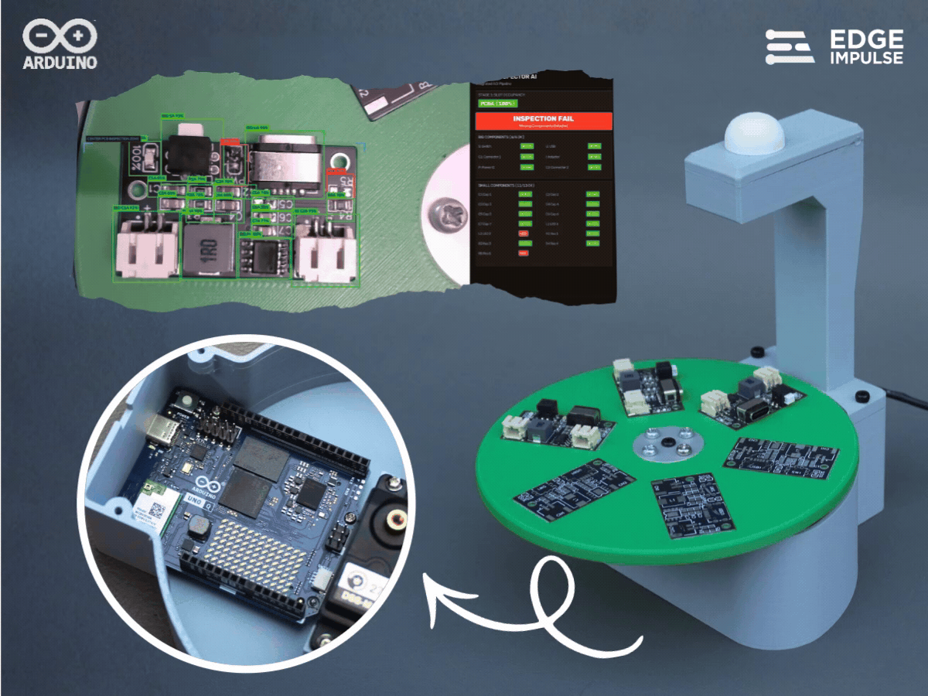
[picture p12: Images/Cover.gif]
Cover


What if a $60 SBC could turn a simple webcam into a complete industrial vision inspection system? That was the idea behind this project. At the heart of the system is the **Arduino UNO Q**, a compact Linux-capable single-board computer that brings enough processing power to run modern AI workloads at the edge. Combined with **Edge Impulse**, it becomes possible to take computer-vision models developed on a PC and bring them directly onto an embedded device for real-time inspection—without relying on the cloud.

For this project, I built a **six-slot rotating vision inspection station** using the Arduino UNO Q, a webcam, and a servo motor. A board placed into one of the six slots is automatically rotated into the inspection position, where the camera captures it and the AI pipeline determines what is present and what needs to be inspected. The system first identifies whether the slot is empty, contains a bare PCB, or contains an assembled PCBA:
- **Bare PCBs** are inspected for scratches and visible surface damage.
- **Assembled PCBAs** go through component-Slevel inspection, verifying both large components (USB-C, JST connectors, switches, power ICs, inductors) and smaller 0805 components (LEDs, resistors, capacitors).

The interesting part is that the AI models were trained separately using **YOLO** and then brought into **Edge Impulse using Bring Your Own Model (BYOM)**. Edge Impulse essentially becomes the bridge between model development and deployment—it packages the models, manages the edge inference pipeline, and makes it much easier to deploy and run the vision workload directly on the UNO Q. The result is a small, self-contained inspection station combining AI vision, robotics, and edge computing into one system.

What started as an experiment with a camera, a rotating platform, and an Arduino UNO Q turned into a miniature automated quality-inspection line—the kind of system that can continuously look at physical products, make decisions locally, and trigger the next action without needing a human to inspect every board.

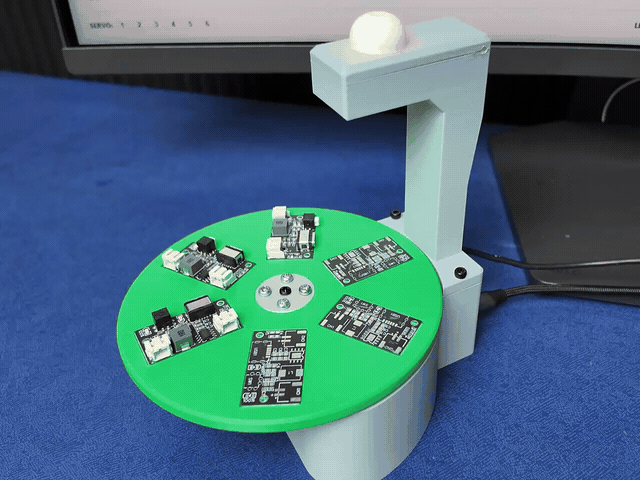
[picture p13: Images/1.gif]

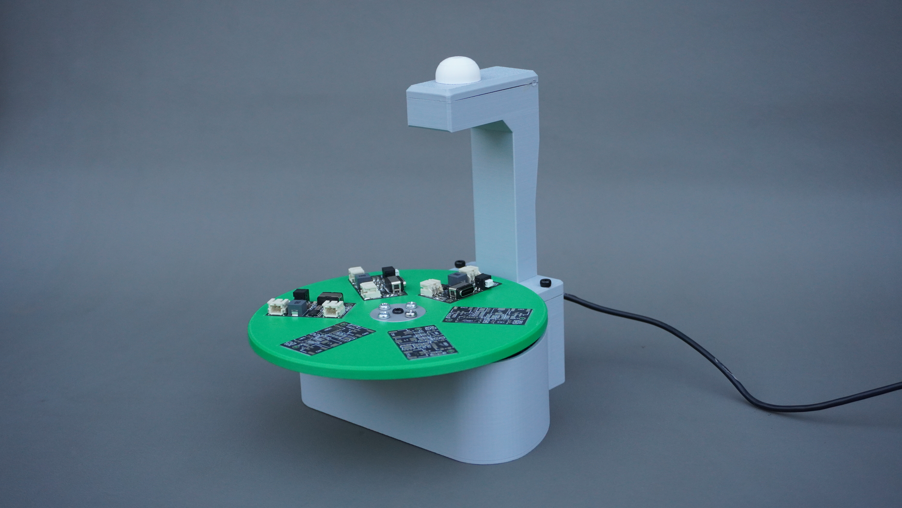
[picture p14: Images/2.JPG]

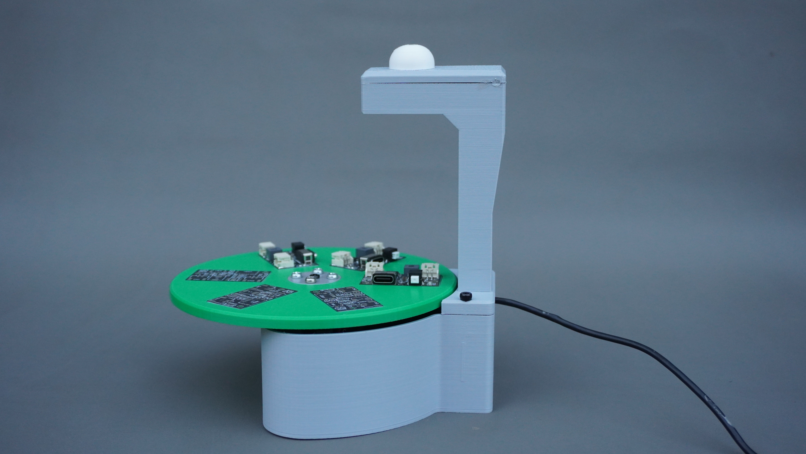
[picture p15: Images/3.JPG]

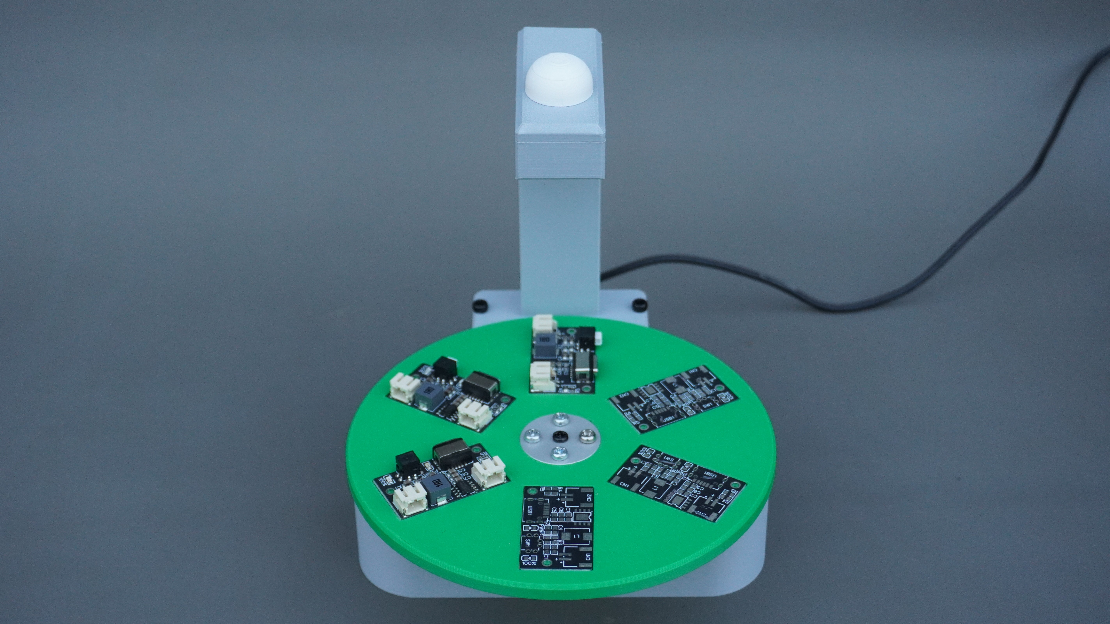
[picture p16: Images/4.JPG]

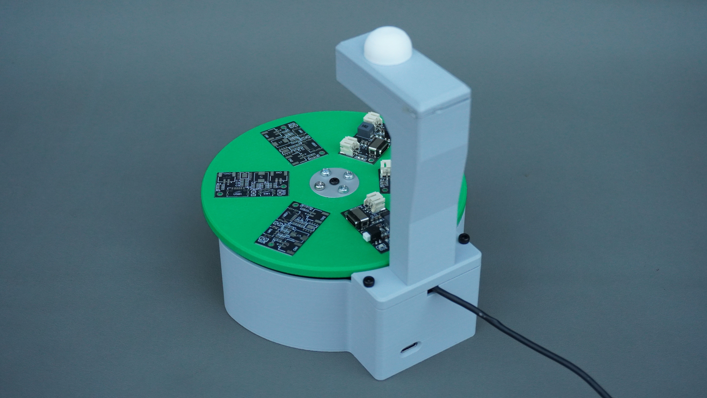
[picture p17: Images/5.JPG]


## Project Resources
- **Author:** [Mukesh Sankhla](https://www.linkedin.com/in/mukeshsankhla/)
- **GitHub Repository:** [Edge AI Vision Inspection](https://github.com/MukeshSankhla/Edge-Ai-Vision-Inspection)
- **CAD Design (Fusion 360):** [Enclosure & Turntable Model](https://a360.co/4xOSRFz)
- **Edge Impulse Public Models:**
  - [Slot Occupancy Detection](https://studio.edgeimpulse.com/public/1123393/live)
  - [PCB Defect Inspection](https://studio.edgeimpulse.com/public/1125264/live)
  - [PCBA Big Component Inspection](https://studio.edgeimpulse.com/public/1125284/live)
  - [PCBA Small Component Inspection](https://studio.edgeimpulse.com/public/1125307/live)

---

## Components

- 1× [Arduino UNO Q](https://www.arduino.cc/product-uno-q)
- 1× [DF Metal Geared 15Kg Standard Servo 270° (DSS-M15S)](https://www.dfrobot.com/product-1177.html)
- 1× [Logitech C270 HD Webcam](https://www.logitech.com/en-in/shop/p/c270-hd-webcam.960-000584)
- 1× [WS2812B RGB LED Module](https://robu.in/product/ws2812b-rgb-addressable-led-module/)
- 1× [USB Hub](https://www.amazon.in/dp/B0BR3M8XHK?ref_=ppx_hzsearch_conn_dt_b_fed_asin_title_1)
- Fasteners & Screws: 4× M2 screws, 4× M3×10mm screws, 4× M3×4mm screws, Servo horn screws

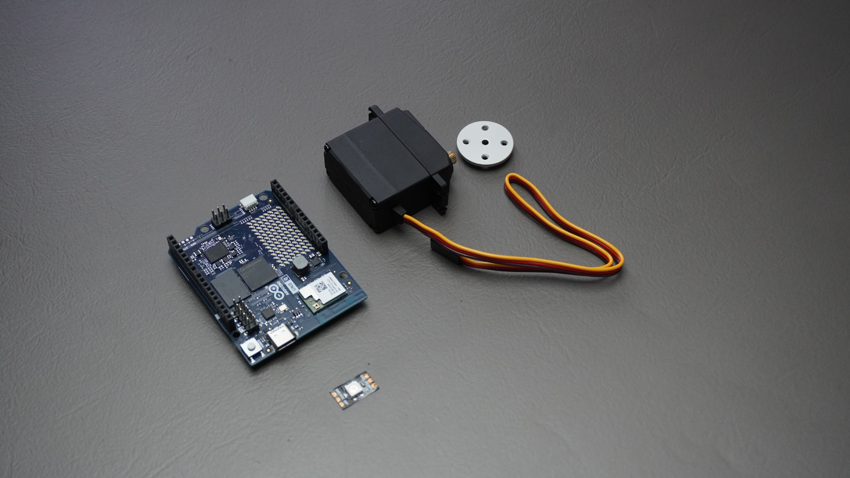
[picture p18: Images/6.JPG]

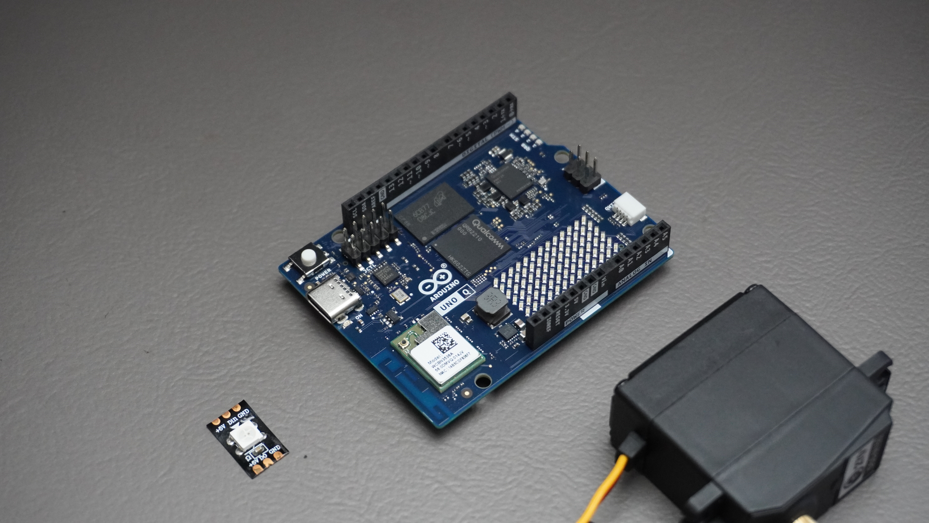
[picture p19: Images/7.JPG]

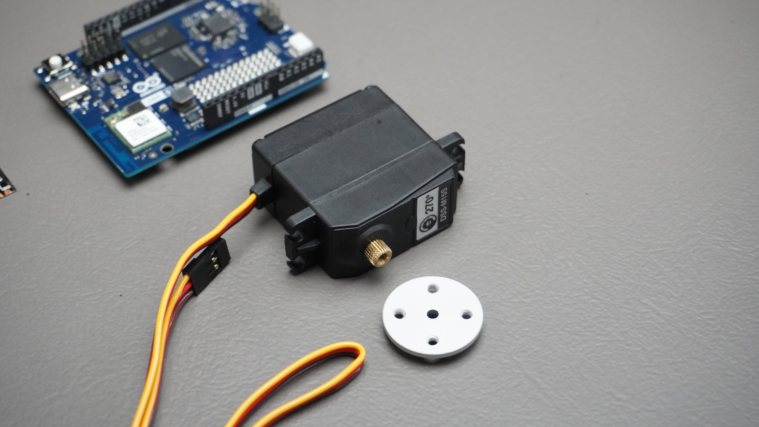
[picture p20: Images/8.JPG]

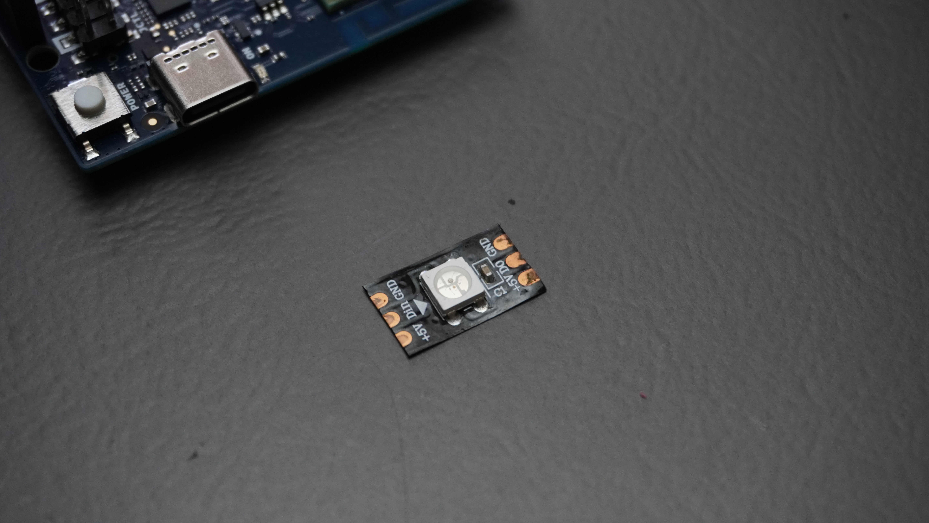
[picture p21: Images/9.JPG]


---

## CAD & 3D Printing

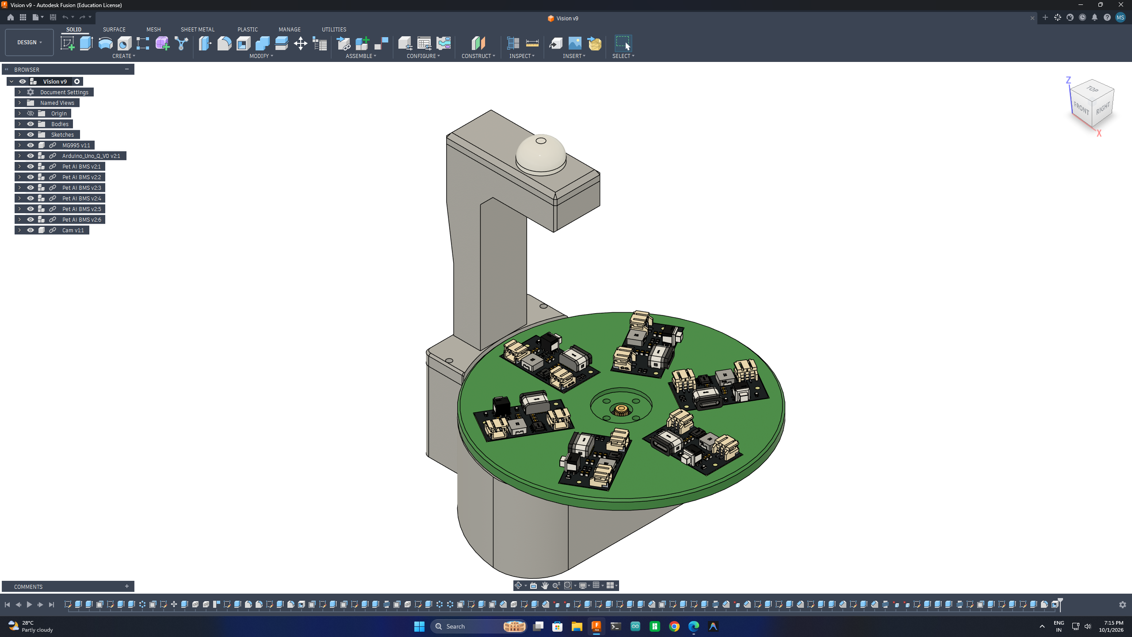
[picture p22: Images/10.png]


To turn the electronics and vision system into a proper standalone inspection station, I designed a custom enclosure in Fusion 360. The design is split into five 3D-printed parts, with each part having a specific role in the system:

- **Main Body**: Houses the Arduino UNO Q and the 360°/270° servo motor.
- **Rotating Plate**: Mounts directly to the servo shaft using the metal horn supplied with the servo. This plate provides the six slots where the PCBs are placed during inspection.
- **Vertical Pole & Pole Mount**: Mounted on the body to act as the rigid housing for the webcam module as well as the RGB status LED.
- **Pole Cover**: Sits on top of the pole to retain the LED and wiring cleanly.
- **Dome Diffuser**: Sits over the RGB LED to spread the light and provide a uniform visual status indicator.

All five parts were designed with easy assembly and accessibility in mind, so the electronics can be installed and serviced without having to redesign the entire enclosure. I 3D-printed the complete enclosure on my **Bambu Lab P1S** using **PLA Pro** and standard print settings. This made it possible to quickly iterate on the mechanical design and build a compact, clean-looking enclosure around the vision inspection system.

* **Fusion 360 Design URL:** [Autodesk Viewer / Download](https://a360.co/4xOSRFz)

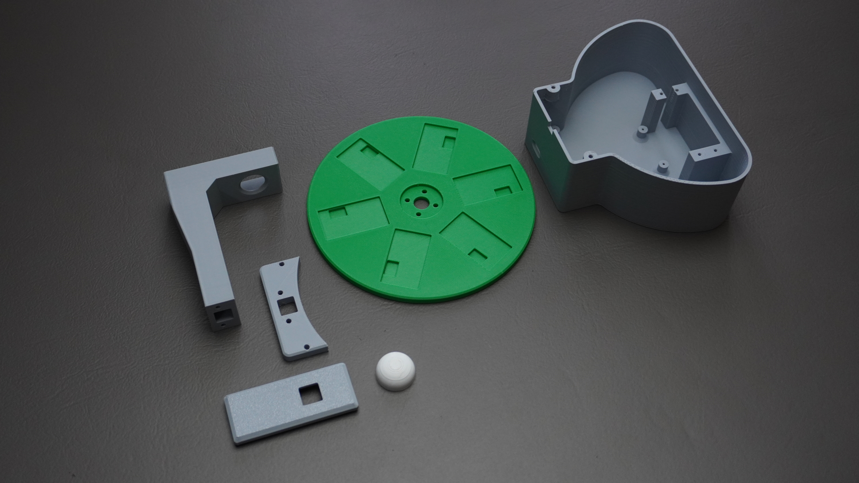
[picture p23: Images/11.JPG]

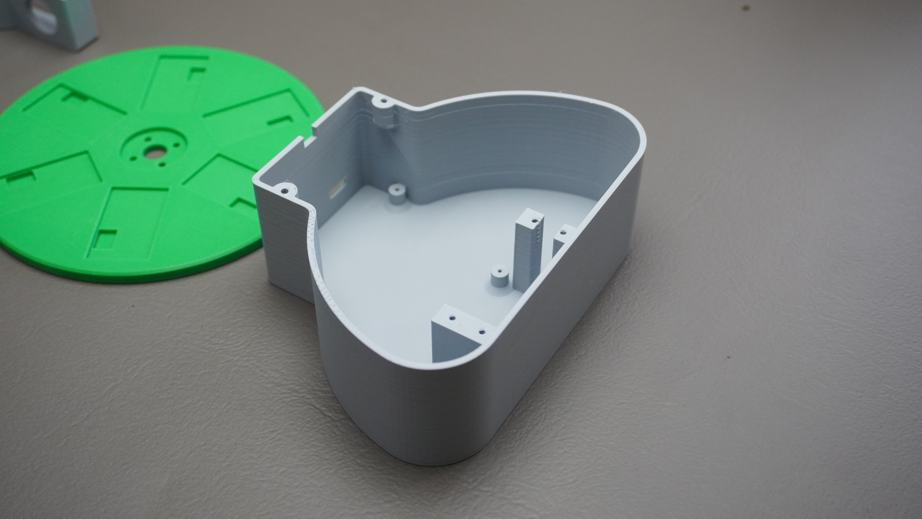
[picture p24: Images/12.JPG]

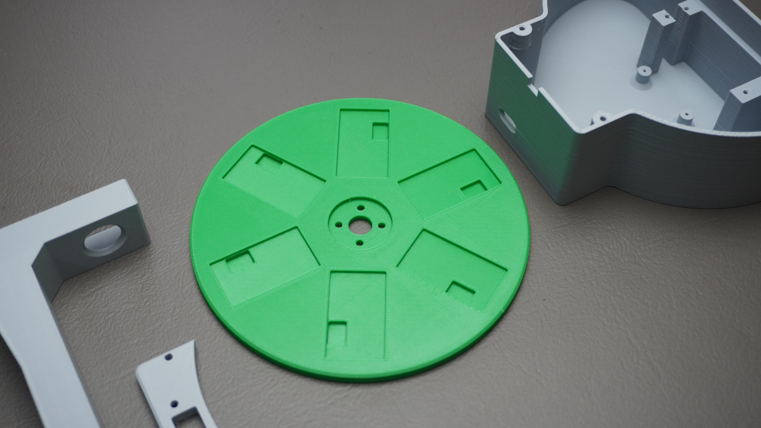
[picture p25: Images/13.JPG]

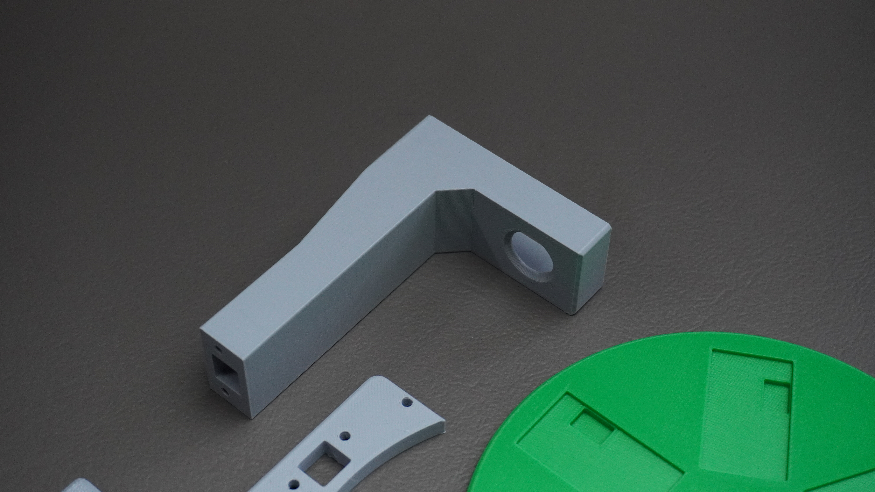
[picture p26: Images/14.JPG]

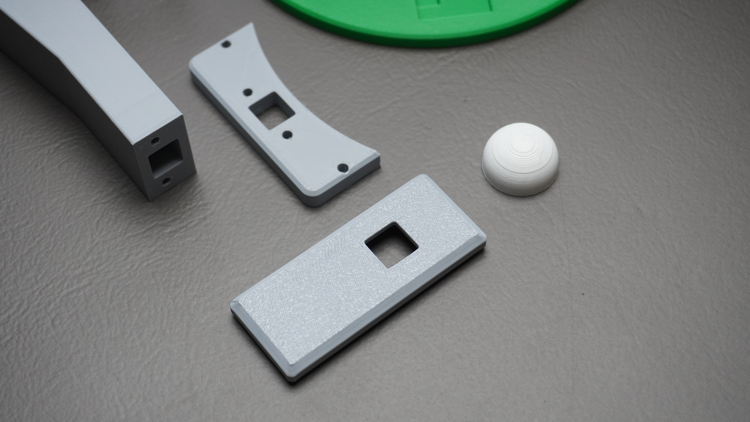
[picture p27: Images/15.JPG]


---

## Assembly Guide

### Servo Assembly

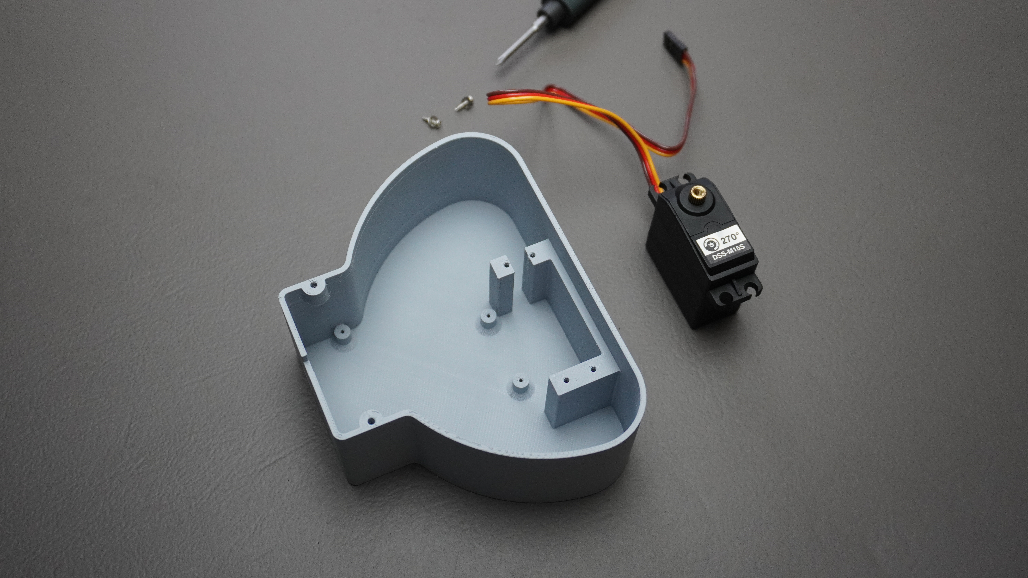
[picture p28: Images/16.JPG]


Start with the 3D-printed Body and the DF DSS-M15S servo. Place the servo into the dedicated mounting slot in the body and align the screw holes with the mounting points. Once aligned, secure the servo using the four screws supplied with the servo. Make sure the servo is firmly mounted and does not move inside the enclosure, as any mechanical play can affect the positioning accuracy of the rotating plate.

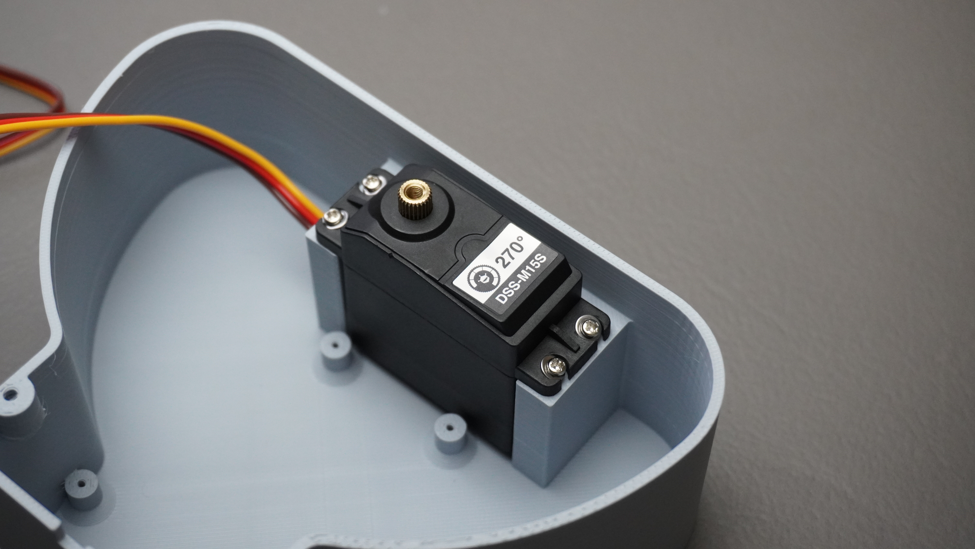
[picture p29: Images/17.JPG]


### Arduino UNO Q Assembly

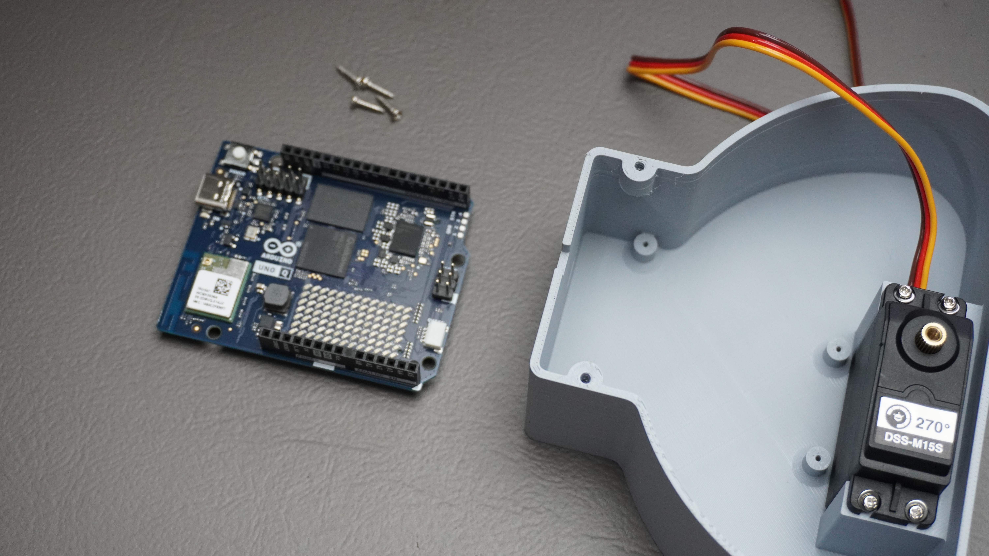
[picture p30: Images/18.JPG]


Next, install the Arduino UNO Q inside the 3D-printed Body. Align the board with the printed standoffs and make sure the USB Type-C port lines up with the opening in the enclosure. Once everything is correctly aligned, secure the Arduino UNO Q using four M2 screws.

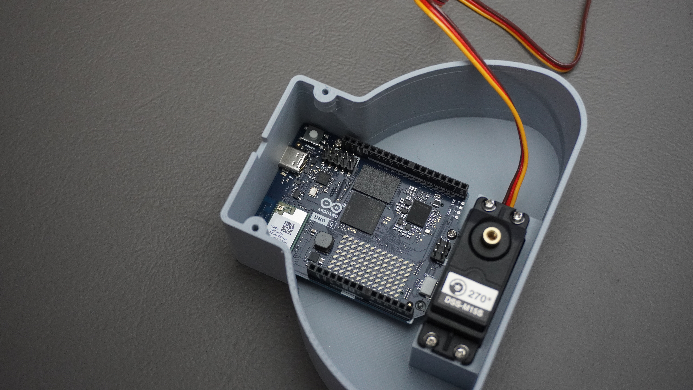
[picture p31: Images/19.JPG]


### Pole Mount Assembly

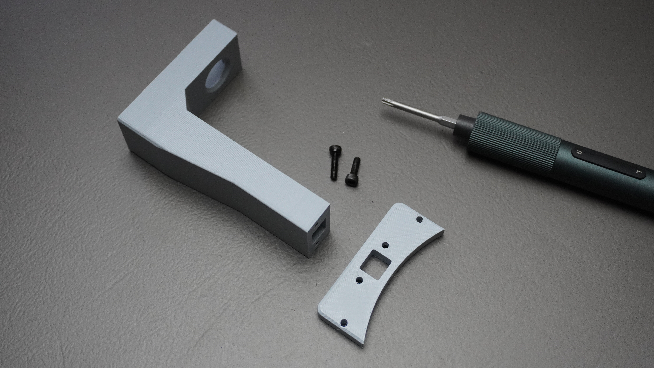
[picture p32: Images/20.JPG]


Take the 3D-printed Pole and Pole Mount and align the two parts together. Secure them using 2 × M3 × 10 mm screws. Make sure the pole is firmly attached, as it will hold the camera and LED assembly above the rotating inspection plate.

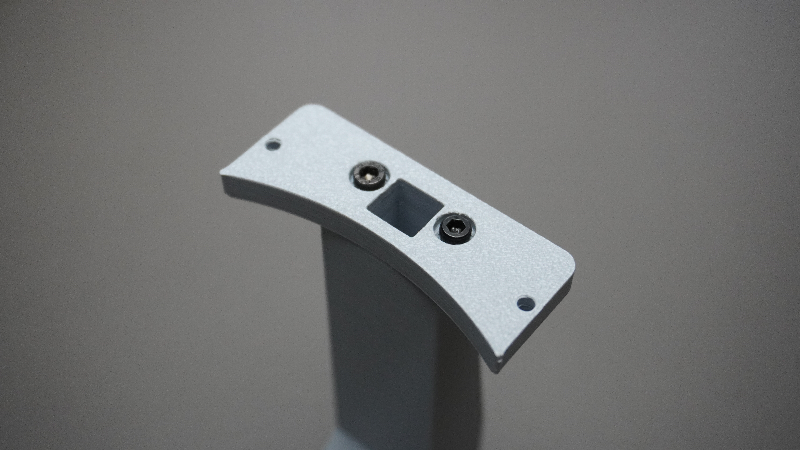
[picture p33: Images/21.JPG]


### Camera & LED Assembly

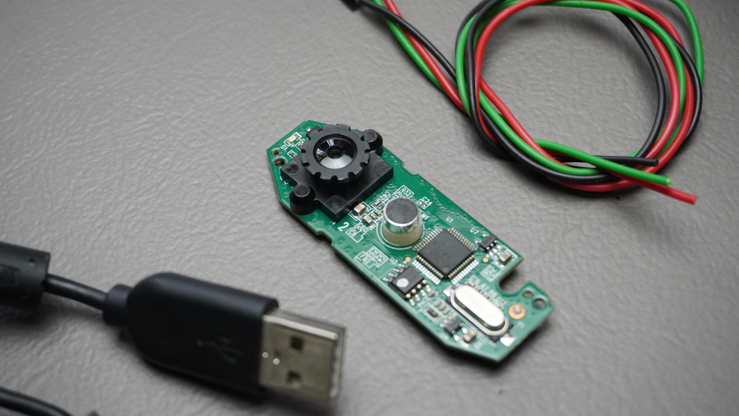
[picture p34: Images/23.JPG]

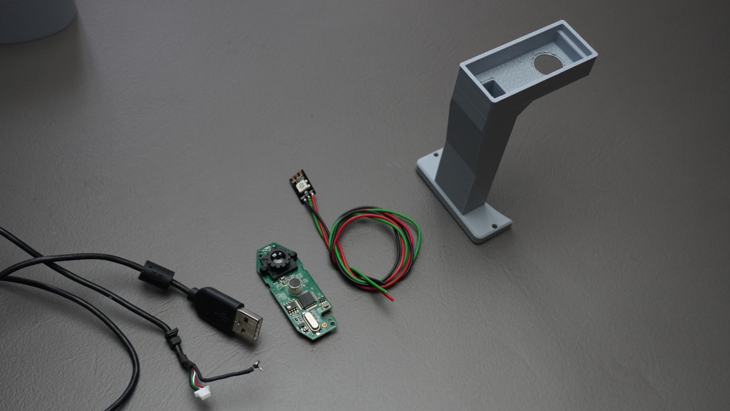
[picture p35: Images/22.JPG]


1. For the camera, first remove the camera PCB from the Logitech C270 housing, leaving the camera module and PCB exposed.
2. Take the camera PCB and carefully slide it into the designated slot inside the 3D-printed Pole. Align the camera with the opening at the top of the pole and route the USB/camera wires through the hollow section of the pole. This keeps the wiring hidden and gives the assembly a clean appearance.
3. Next, prepare the WS2812B RGB LED by soldering three wires to it:
   - **GND**
   - **5V**
   - **S-IN** (Data)
4. Route these wires through the hollow section of the pole as well.
5. Now take the Pole Cover and mount the WS2812B LED into the dedicated LED opening. Apply a small amount of glue to secure the LED in place.
6. Finally, snap the Pole Cover onto the top of the Pole. The cover should fit securely. If the fit is slightly loose, apply a small amount of quick-setting glue to hold it in place.

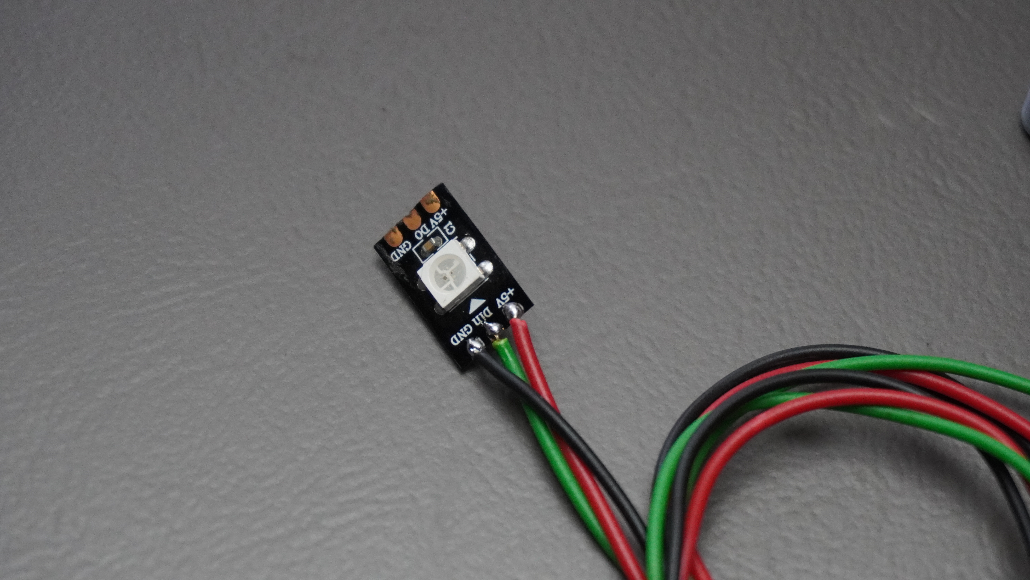
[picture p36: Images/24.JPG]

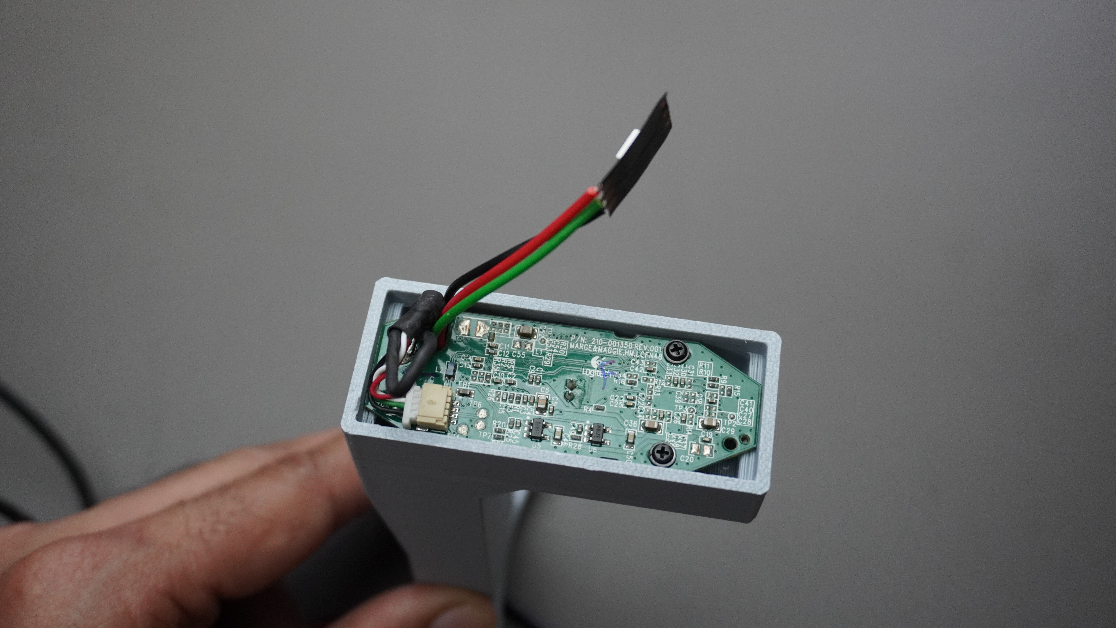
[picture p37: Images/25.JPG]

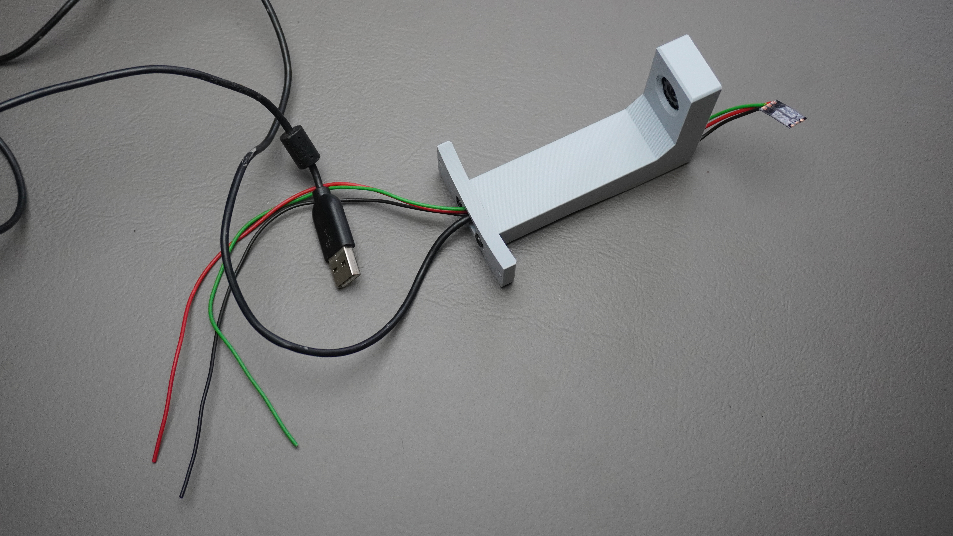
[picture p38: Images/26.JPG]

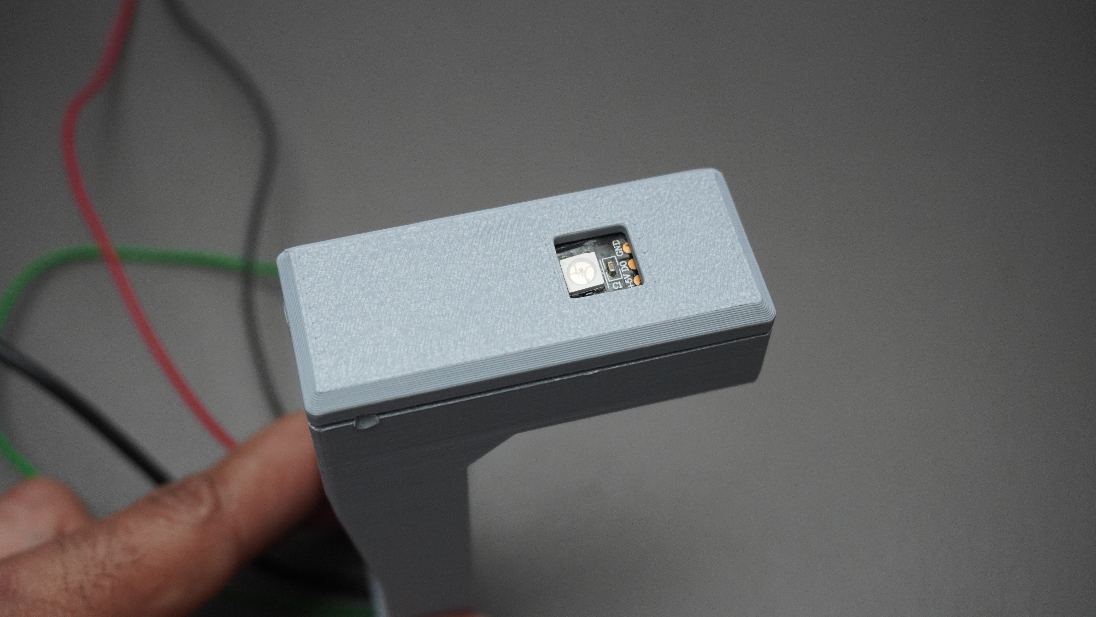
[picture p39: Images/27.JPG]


### Connections
To connect the WS2812B RGB LED and the servo motor to the Arduino UNO Q, first prepare a few header pins and solder the connections as follows:

| Peripheral | Connection Wire | Arduino UNO Q Header Pin |
| :--- | :--- | :--- |
| **Servo GND & LED GND** | Solder together to a single header pin | **GND** |
| **Servo 5V & LED 5V** | Solder together to a single header pin | **5V** |
| **Servo Signal** | Signal wire to header pin | **Pin 9** |
| **LED S-IN (Data)** | Data wire to header pin | **Pin 8** |

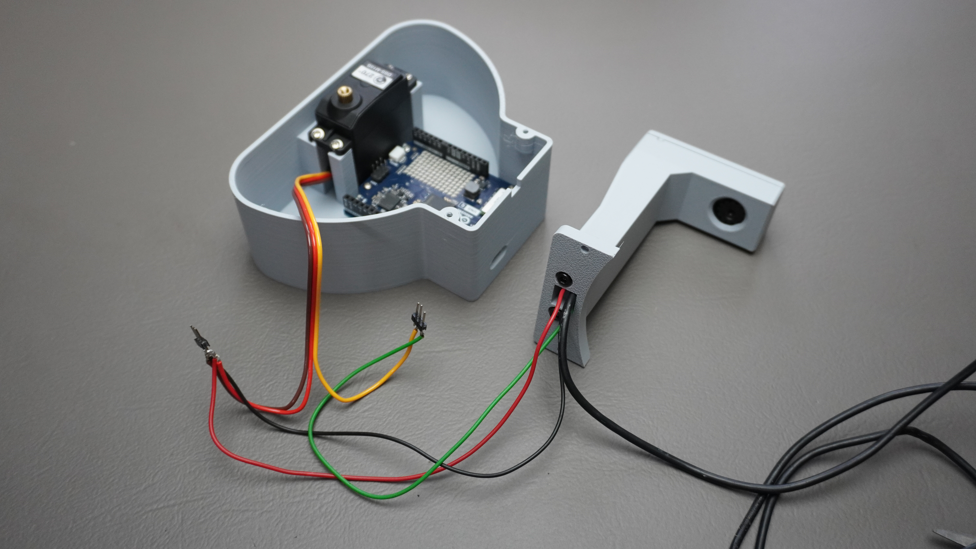
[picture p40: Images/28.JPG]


### Pole and Body Assembly

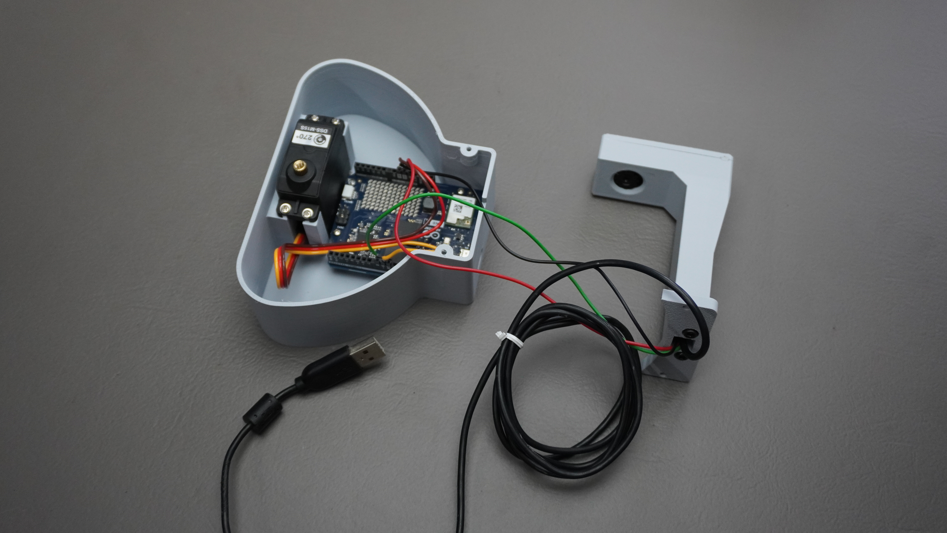
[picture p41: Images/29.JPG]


Now it's time to attach the completed Pole Assembly to the main Body. Align the Pole Assembly with the mounting points on the Body and make sure the camera USB cable is correctly routed through the designated opening. Before tightening the screws, neatly manage the excess camera and RGB LED wires inside the Body so they do not interfere with the servo or rotating mechanism.

Once everything is properly aligned and the wiring is clear, secure the Pole Assembly to the Body using 2 × M3 × 10 mm screws.

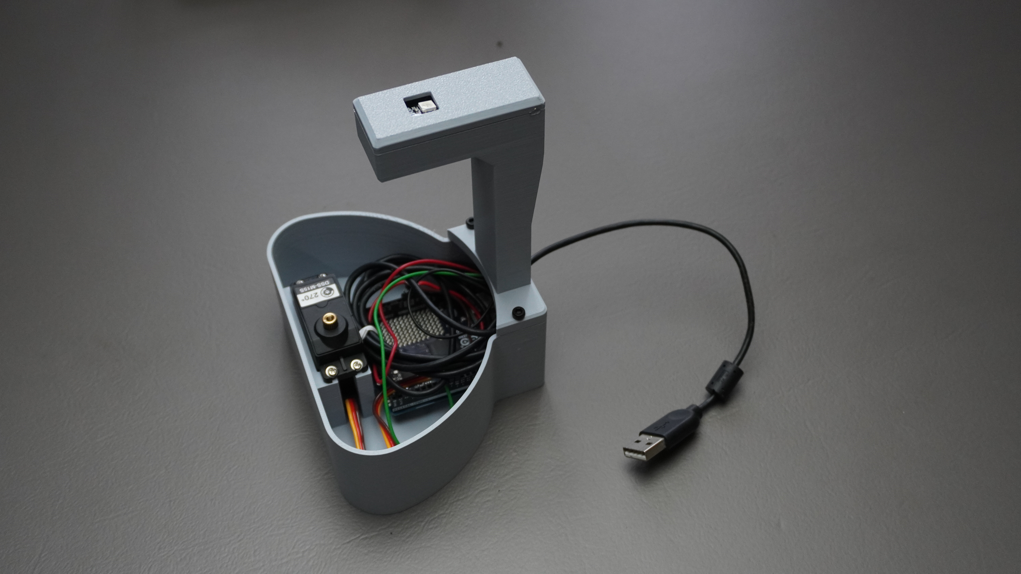
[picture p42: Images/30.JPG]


### Rotating Plate Assembly

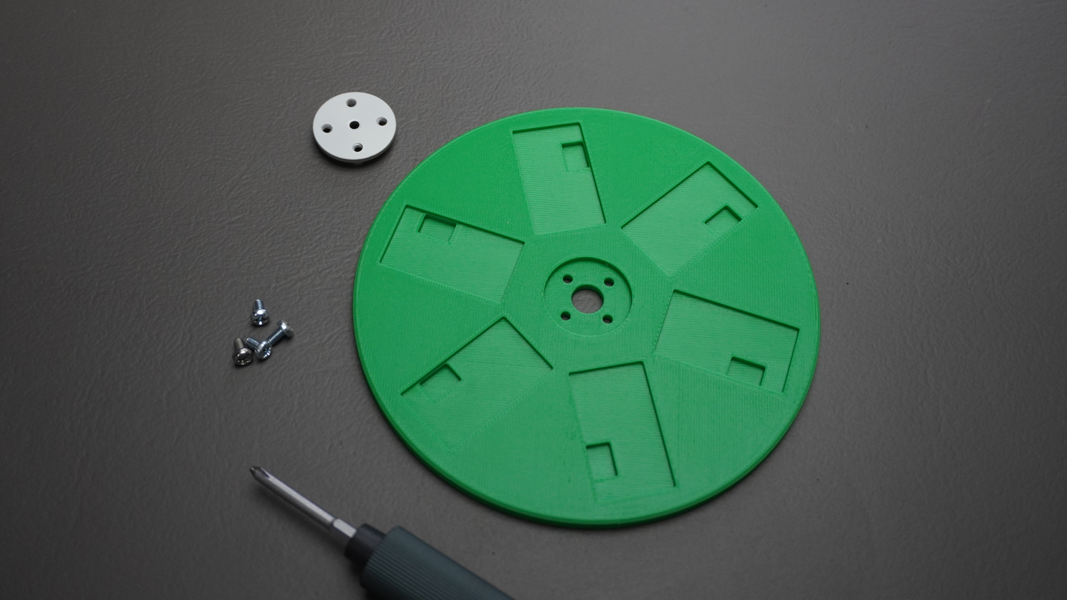
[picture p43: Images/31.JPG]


1. Take the 3D-printed Rotating Plate and the servo horn that came with the servo. Align the servo horn with the mounting points on the Rotating Plate and snap it into position.
2. Secure the servo horn to the Rotating Plate using 4 × M3 × 4 mm screws.
3. Next, take the completed Rotating Plate assembly and align the servo horn with the servo shaft already mounted in the Body. Carefully press the assembly onto the servo shaft, making sure it is properly seated and aligned.
4. Finally, use the servo screw supplied with the servo to secure the Rotating Plate assembly to the servo shaft.

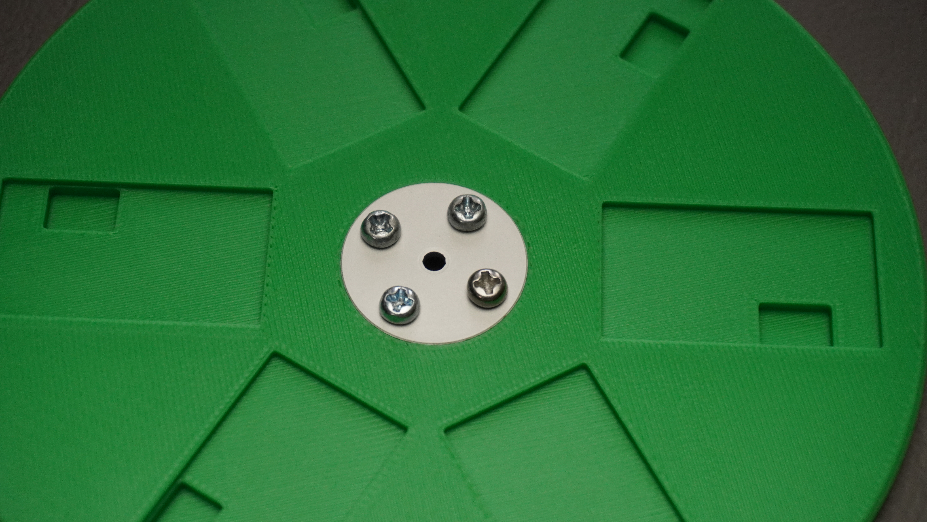
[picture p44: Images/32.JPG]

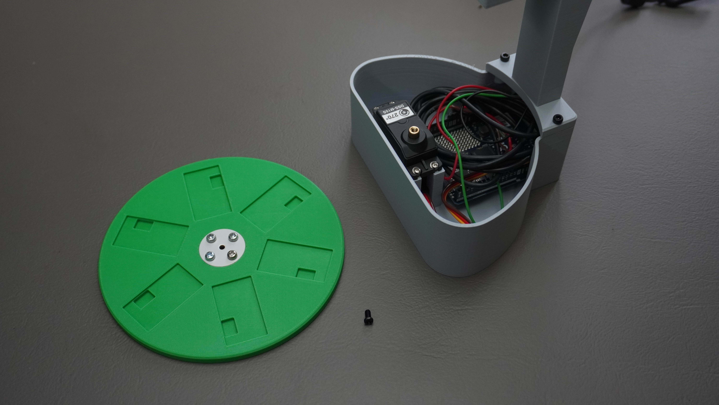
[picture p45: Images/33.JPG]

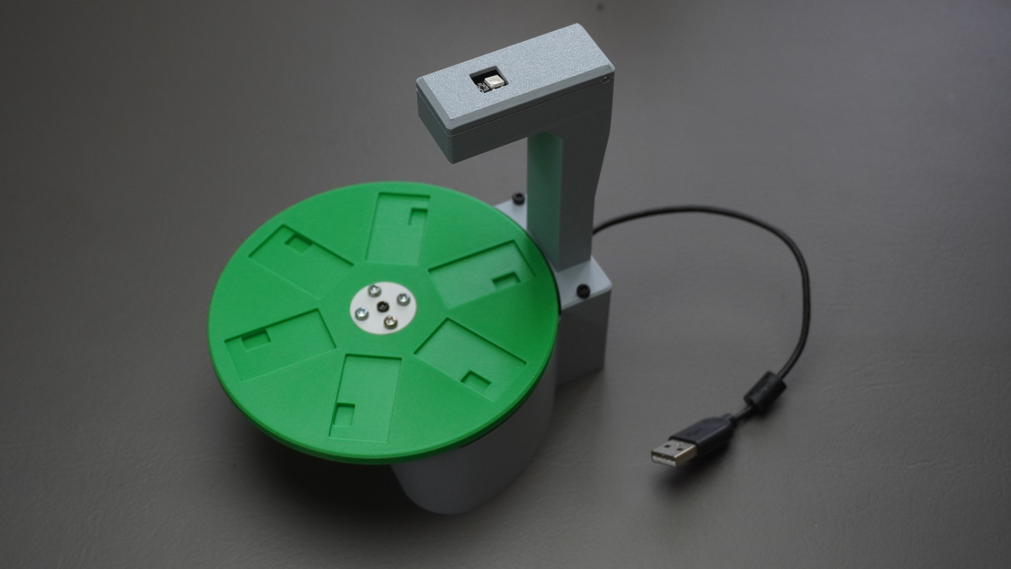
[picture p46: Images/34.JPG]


And that's it! The mechanical assembly is complete.

---

## Training the Machine Learning Models

As mentioned earlier, for this project I am using a custom battery charging and discharging circuit PCB, but the same approach can be applied to almost any PCB or PCBA depending on your inspection requirements.

The first step is to build the dataset for each of the four vision models. Since the final system will use the same webcam and camera position, it is important to capture the training images using the same camera and setup that will be used during the actual inspection. I connected the webcam to my PC, opened the Camera app, and captured multiple images of the different inspection conditions. I captured images of an empty slot, bare PCB, and assembled PCBA, along with different examples of the defects and components that I wanted the models to learn. In general, having more representative images for each condition gives the model more examples to learn from and can help improve its ability to generalize.

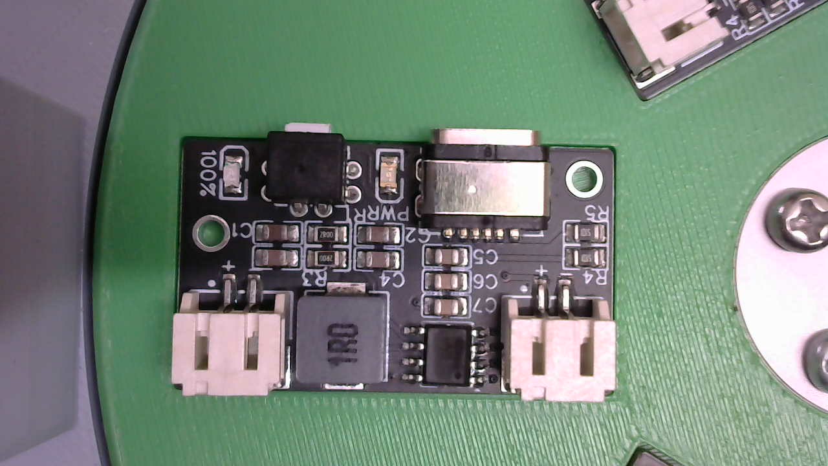
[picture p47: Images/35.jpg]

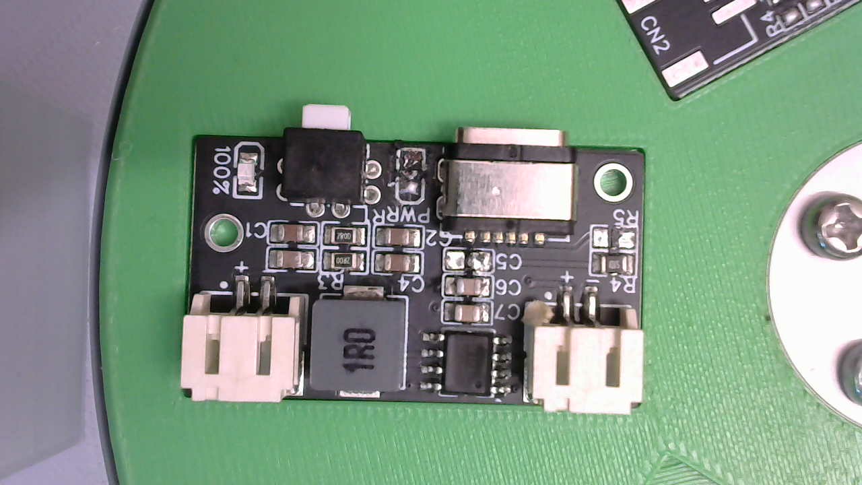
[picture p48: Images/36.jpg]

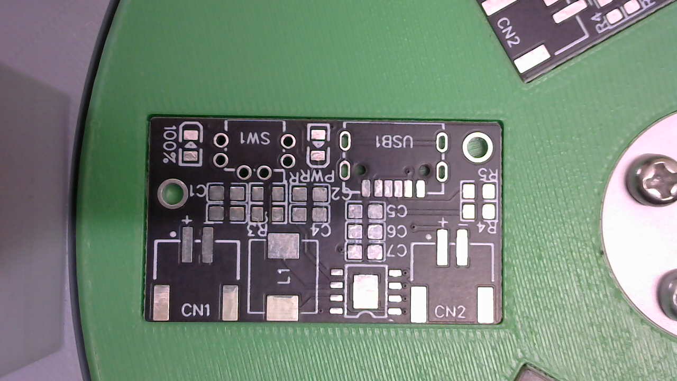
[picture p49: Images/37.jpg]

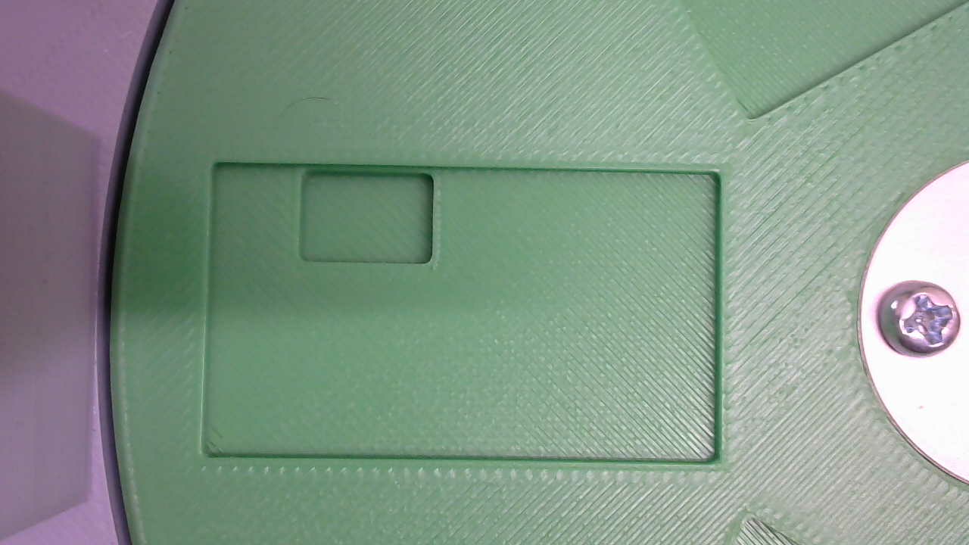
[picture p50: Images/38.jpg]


Once the images were collected, I imported the dataset into [Make Sense](https://www.makesense.ai/), an online annotation tool, and started labeling the images according to the requirements of each model.

### Model Classes & Annotations

1. **Slot Occupancy Model (Image Classification):**
   - `Empty`
   - `PCB`
   - `PCBA`

2. **PCB Inspection Model (Object Detection):**
   - `Issue / Scratch` — Used to identify visible scratches or damage on the PCB surface.

3. **PCBA Big Component Inspection Model (Object Detection):**
   Classes based on the component type and whether the component is present (`A` = Available) or missing (`N` = Not Available):
   - `SA` / `SN` — SMD Switch Available / Not Available
   - `UA` / `UN` — USB Type-C Available / Not Available
   - `C1A` / `C1N`, `C2A` / `C2N` — JST Connector 1/2 Available / Not Available
   - `IA` / `IN` — Inductor Available / Not Available
   - `PA` / `PN` — Power IC Available / Not Available

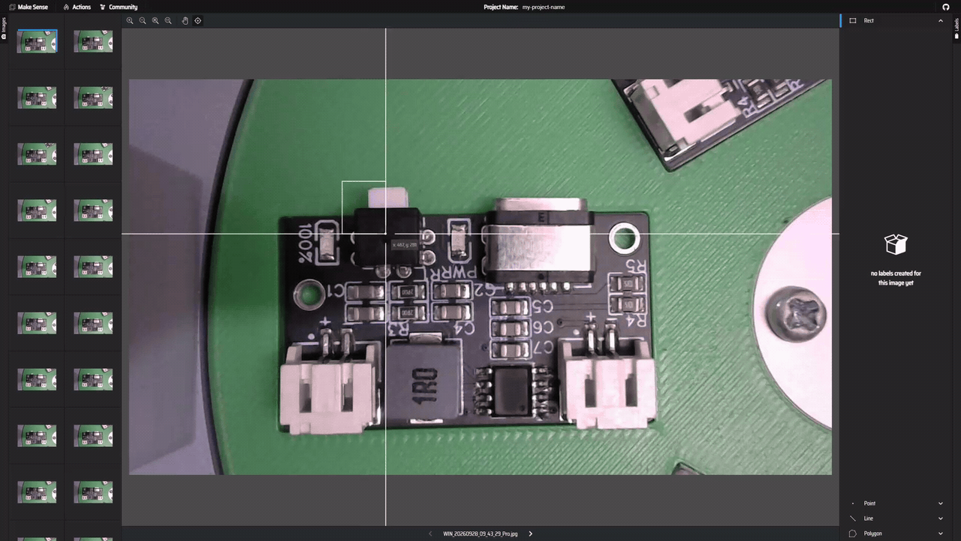
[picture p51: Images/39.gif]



4. **PCBA Small Component Inspection Model (Object Detection for 0805 components):**
   - `L1A` / `L1N`, `L2A` / `L2N` — LEDs
   - `C1A` / `C1N` through `C7A` / `C7N` — Capacitors
   - `R1A` / `R1N`, `R3A` / `R3N`, `R4A` / `R4N`, `R5A` / `R5N` — Resistors

This naming convention makes it easier for the final application to understand not only which component it is looking at, but also whether that component is present or missing.

After annotating all the images, I exported the annotations from Make Sense as a single CSV file. This labeled dataset is then used as the foundation for training the individual machine-learning models.

### Dataset Organization



Before moving on to model training, make sure the datasets are organized properly. Since we are training four different models, I recommend keeping each model's dataset completely separate:

```text
Main Folder/
│
├── Slot Occupancy/
│   └── dataset/
│       ├── training/
│       ├── testing/
│       └── Label.csv
│
├── PCB Inspection/
│   └── dataset/
│       ├── training/
│       ├── testing/
│       └── Label.csv
│
├── PCBA Big Comp Inspection/
│   └── dataset/
│       ├── training/
│       ├── testing/
│       └── Label.csv
│
└── PCBA Small Comp Inspection/
    └── dataset/
        ├── training/
        ├── testing/
        └── Label.csv
```

Each model has its own dataset folder, containing separate training and testing images along with the corresponding `Label.csv` file. Keeping the four datasets isolated is important because each model has a different purpose and different set of classes.

---

## Preparing the Dataset for YOLO Training

Once the images have been captured and annotated in MakeSense, the next step is to convert the dataset into the format required by YOLO. The original dataset contains the captured images and the `labels_makesense.csv` annotation file. For the example Big Component Inspection model, the dataset contains 44 images and 264 bounding-box annotations, split into 36 training images and 8 testing images.

The MakeSense annotations are then converted into the standard YOLO dataset structure:

```text
yolo_dataset/
│
├── images/
│   ├── train/
│   └── val/
│
├── labels/
│   ├── train/
│   └── val/
│
└── data.yaml
```

Before training, run a dataset verification step to make sure the images and annotations are valid. This checks that the bounding boxes are correctly formatted and remain within the valid image boundaries.

> [!IMPORTANT]
> One critical detail in this project is that the components are mounted in fixed physical positions on the PCB. Because of this, **horizontal and vertical image flipping were disabled during augmentation**. Flipping the image could effectively swap components from one side of the PCB to another and teach the model an incorrect spatial relationship.

---

## Training & Evaluating the YOLO Model

### Training the YOLO Model
For this project, I used **YOLO11 Nano (`yolo11n.pt`)**, a lightweight object-detection model that is well suited for edge deployment. The model was trained for 80 epochs with an image size of 640 × 640, a batch size of 8, and an NVIDIA RTX 5070 Ti GPU.

The training was executed using:
```bash
python train.py --epochs 80 --batch 8 --device 0
```

The training process took approximately 48 seconds for 80 epochs on the RTX 5070 Ti. During training, the model learns the visual characteristics of each component and the difference between the Available (A) and Not Available/Missing (N) classes.








### Evaluating and Testing the YOLO Model
After training the YOLO model, the next step is to evaluate its performance using the validation dataset.

For the example Big Component Inspection model:
- **Precision:** 97.94%
- **Recall:** 100%
- **mAP@0.5:** 99.50%
- **mAP@0.5:0.95:** 89.60%





After checking the numerical metrics, I also performed test inference on the images to visually verify the detections. The model correctly identified all six large components on fully populated boards and classified the corresponding components as missing on bare/unpopulated boards. Visual verification confirms that bounding boxes are correctly positioned and that the model detects the expected components before moving to deployment.

---

## Exporting the YOLO Model to ONNX

Once the YOLO model has been trained and tested successfully, the next step is to export the best model into ONNX (Open Neural Network Exchange) format:

- **Saved Path:** `runs/train/weights/best.onnx`
- **Model Size:** ~10.1 MB
- **Opset Version:** 17/18
- **Graph Optimization:** Optimized using `onnxslim` to reduce unnecessary overhead while keeping the trained model intact.
- **Input Shape:** `[1, 3, 640, 640]` in `float32` format.
- **Output Shape:** `[1, 16, 8400]`, containing bounding-box coordinates and confidence scores for the 12 large-component classes.
- **Inference Speed:** ~3.2 ms per image in ONNX Runtime.

---

## Importing the YOLO Model into Edge Impulse (BYOM)

The same training process is followed for the other inspection models. Once the models are exported to ONNX, we bring them into Edge Impulse using Bring Your Own Model (BYOM).

### Creating the Edge Impulse Project




1. Open [Edge Impulse Studio](https://studio.edgeimpulse.com/) and log into your account.
2. Click **Create New Project** and enter a name.
3. In the project dashboard, click **Upload your Model**.
4. Select the `weights/best.onnx` file generated during the YOLO training process.
5. When Edge Impulse asks whether you want performance characteristics (latency, RAM, ROM) for a specific device, select **Yes**.
6. Select **Arduino Uno Q** as the target device.
7. Click **Upload**.




### Configuring the Imported Model



Use the following settings:
- **Model Input:** Image
- **Model Output:** Object Detection
- **Resize Mode:** Fit Long Axis
- **Output Layer:** YOLOv11 (Coordinates in absolute values)
- **Output Labels:** Match the class names used when training the YOLO model.
- Click **Save**.

### Why Use Edge Impulse If We Already Have a YOLO Model?
1. **Customization:** With BYOM, we are not restricted to only models trained inside Edge Impulse. We can train separate YOLO models specifically for slot occupancy, PCB inspection, and PCBA component inspection using standard PyTorch/Ultralytics pipelines.
2. **Performance Optimization:** Edge Impulse profiles and optimizes the model specifically for the target hardware (Qualcomm QRB2210 Linux MPU on the Arduino UNO Q).
3. **Faster Deployment:** Packaging models into standalone `.eim` executable binaries removes external Python runtime overhead and makes deployment seamless.
4. **Flexibility:** Keeps a modular workflow:
   $$\text{Custom Dataset} \rightarrow \text{YOLO Training} \rightarrow \text{Validation} \rightarrow \text{ONNX} \rightarrow \text{Edge Impulse BYOM} \rightarrow \text{Arduino UNO Q Deployment}$$

### Testing and Building the Model
- In Edge Impulse, upload validation images to **Data Acquisition**, go to **Model Testing**, and click **Classify All**.




#### Public Model Links
- [Slot Occupancy Model](https://studio.edgeimpulse.com/public/1123393/live)
- [PCB Defect Inspection Model](https://studio.edgeimpulse.com/public/1125264/live)
- [PCBA Big Component Inspection Model](https://studio.edgeimpulse.com/public/1125284/live)
- [PCBA Small Component Inspection Model](https://studio.edgeimpulse.com/public/1125307/live)

---

## Deploying the Vision Inspection System on Arduino UNO Q

- You can also use **Live Classification** directly in the browser to point your webcam at the PCB/PCBA and inspect real-time predictions.
- On the **Deployment** page, select **Arduino UNO Q** and click **Build** to download the standalone `.eim` executable binary.



With all four `.eim` files ready, we deploy the complete system to the Arduino UNO Q:

```text
BMS EIM Vision Inspection/
│
├── arduino_firmware/
│   └── bms_servo_led/
│       └── bms_servo_led.ino
│
├── models/
│   ├── slot-occupancy.eim
│   ├── pcb-inspection.eim
│   ├── big-components-inspection.eim
│   └── small-components-inspection.eim
│
├── snapshots/
├── bms_eim_vision_inspection.py
├── requirements.txt
└── README.md
```



### Inspection Pipeline Flow
1. **Camera Acquisition:** The webcam continuously captures the inspection area.
2. **Slot Occupancy:** Stage 1 runs `slot-occupancy.eim`.
   - If **Empty**: Inspection for this slot is skipped.
   - If **PCB**: Runs `pcb-inspection.eim` to check for scratches and defects.
   - If **PCBA**: Runs `big-components-inspection.eim` and `small-components-inspection.eim` to verify all components.
3. **PASS / FAIL Logic:** Determines pass/fail status based on missing parts or detected defects.
4. **Hardware Action:** Sends RPC commands to the Arduino firmware to set the WS2812B RGB LED color and rotate the servo turntable to the next slot.
5. **Web Dashboard:** Hosts a live interface on port 5000 to display camera frames, bounding boxes, and pass/fail counts.

```
Camera ──> Slot Occupancy ──> PCB/PCBA Inspection ──> PASS/FAIL ──> RGB LED ──> Rotate to Next Slot
```

### Arduino UNO Q Dual-Domain Architecture (MPU + MCU)
The UNO Q features two separate processors:
- **Qualcomm MPU (Linux):** Runs the Python application, webcam capture, Edge Impulse `.eim` models, inspection logic, and Flask web dashboard.
- **STM32U585 MCU (Zephyr / Arduino):** Handles real-time hardware execution: servo motor PWM on Pin 9 and WS2812B addressable LED data on Pin 8.

Communication uses Arduino's **MessagePack RPC bridge** via a Unix domain socket:

```text
Python Application (MPU)
          ↓
Arduino Router (/var/run/arduino-router.sock)
          ↓
MessagePack RPC
          ↓
STM32U585 MCU (Zephyr)
          ↓
Servo (Pin 9) + WS2812B RGB LED (Pin 8)
```

This clean separation allows the Linux MPU to focus on computer vision and inference, while the MCU handles deterministic real-time hardware timing.

---

## Step-by-Step Setup & Execution

### 1. Flash Arduino Firmware



1. Open the Arduino IDE on your computer.
2. Open [`bms_servo_led.ino`](file:///c:/Users/MAKERBRAINS/Downloads/Edge%20Ai%20Vision%20Inspection/BMS%20EIM%20Vision%20Inspection/arduino_firmware/bms_servo_led/bms_servo_led.ino) located in:
   `BMS EIM Vision Inspection/arduino_firmware/bms_servo_led/bms_servo_led.ino`
3. Select board **Arduino UNO Q** and the corresponding port.
4. Click **Upload**.
5. Once complete, the RGB LED illuminates **green** and the turntable positions itself to **home (0°)**.

### 2. Aligning the Rotating Plate
Check whether the first slot is aligned with the camera. If it is slightly off, loosen the center servo horn screw, manually rotate the plate to exact center, and re-tighten. This sets the mechanical home position.

### 3. Deploying to the Arduino UNO Q
1. Connect the Arduino UNO Q to a powered USB hub and connect the webcam to the same hub.
2. Identify your UNO Q's IP address (e.g., `192.168.1.18`).
3. Copy the project folder to the UNO Q using `scp`:
   ```bash
   scp -r "BMS EIM Vision Inspection" arduino@192.168.1.18:~/Downloads/
   ```
4. SSH into the UNO Q:
   ```bash
   ssh arduino@192.168.1.18
   ```
5. Set up the Python environment:
   ```bash
   cd ~/Downloads/"BMS EIM Vision Inspection"
   sudo apt update
   sudo apt install python3 python3-venv python3-pip -y
   python3 -m venv .venv
   source .venv/bin/activate
   pip install -r requirements.txt
   chmod +x models/*.eim
   ```
6. Start the inspection application:
   ```bash
   python bms_eim_vision_inspection.py --source 0
   ```
   *(If your webcam is assigned to a different index, try `--source 1` or `--source 2`).*



### 4. Running the Application on Subsequent Boots
```bash
ssh arduino@192.168.1.18
cd ~/Downloads/"BMS EIM Vision Inspection"
source .venv/bin/activate
python bms_eim_vision_inspection.py --source 0
```

### 5. Accessing the Web Dashboard
Open any browser on the local network and navigate to:
```text
http://192.168.1.18:5000/
```






The web dashboard displays:
- Live inspection camera stream with detection overlays
- Current slot number and inspection status (Empty, PCB, PCBA, Pass/Fail)
- Manual turntable indexing and home calibration controls
- Captured defect snapshots and inspection history

---

## Conclusion




This project demonstrates how edge AI turns low-cost hardware into an industrial-grade vision inspection station. By combining mechanical 3D design, custom YOLO11 models, Edge Impulse BYOM packaging, and the dual-brain Arduino UNO Q, we created a self-contained, real-time AOI system that operates entirely offline without cloud dependencies.

The core workflow:
$$\text{Define Inspection} \rightarrow \text{Design Hardware} \rightarrow \text{Collect Data} \rightarrow \text{Train YOLO} \rightarrow \text{Optimize via BYOM} \rightarrow \text{Deploy to UNO Q} \rightarrow \text{Automate}$$

This blueprint can be directly adapted for manufacturing quality control, assembly verification, packaging inspection, sorting, and edge robotics.

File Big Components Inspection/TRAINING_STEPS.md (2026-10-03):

# Big Components Inspection - YOLO Vision Model Training Documentation

This document provides a comprehensive, step-by-step record of the training, validation, evaluation, and export of the YOLO object detection model for the **Big Components Inspection** project.

---

## 1. Project Overview & Inspection Objective

### 1.1 Objective
The purpose of this project is Automated Optical Inspection (AOI) of large electronic components on circuit boards or mechanical assemblies. The visual inspection system detects whether each designated component is **Present / Available (`A`)** or **Absent / Missing (`N`)**.

### 1.2 Inspection Zones & Classes
There are **6 physical component locations** on each board, producing **12 distinct detection classes**:

| Component Code | Component Description | Present / Available (`A`) | Absent / Missing (`N`) |
| :--- | :--- | :--- | :--- |
| **C1** | Capacitor 1 (Bottom Left) | `C1A` | `C1N` |
| **C2** | Capacitor 2 (Bottom Right) | `C2A` | `C2N` |
| **I** | Inductor (Bottom Center-Left) | `IA` | `IN` |
| **P** | Power / Port / Plug (Bottom Center-Right) | `PA` | `PN` |
| **S** | Socket / Sensor / Switch (Top Left) | `SA` | `SN` |
| **U** | IC / Processing Unit (Top Right) | `UA` | `UN` |

Each inspection image contains exactly 6 annotations corresponding to these six locations.

---

## 2. Hardware and Software Environment

- **Operating System:** Windows 11
- **Python Version:** 3.14.6
- **Deep Learning Framework:** PyTorch 2.14.0+cu130
- **Computer Vision Framework:** Ultralytics YOLO v8.4.164
- **Accelerator / GPU:** NVIDIA GeForce RTX 5070 Ti (17 GB VRAM)
- **CUDA Support:** CUDA 13.0 Enabled

---

## 3. Step-by-Step Training Workflow

```
[Raw Dataset]
  ├── dataset/labels_makesense.csv (264 annotations)
  ├── dataset/train/ (36 images)
  └── dataset/test/ (8 images)
         │
         ▼
[Step 1 & 2: Dataset Formatting] ──> convert_makesense_to_yolo.py
         │
         ▼
[YOLO Dataset Structure]
  ├── yolo_dataset/images/train/ (36 images)
  ├── yolo_dataset/images/val/ (8 images)
  ├── yolo_dataset/labels/train/ (36 txt files, 216 bboxes)
  ├── yolo_dataset/labels/val/ (8 txt files, 48 bboxes)
  └── data.yaml
         │
         ▼
[Step 3: Verification] ──> verify_dataset.py (Integrity & BBox check)
         │
         ▼
[Step 4 & 5: Model Training] ──> train.py (YOLO11n, 80 epochs on RTX 5070 Ti)
         │
         ▼
[Step 6: Evaluation & Metrics] ──> mAP@50: 99.5%, Precision: 97.9%, Recall: 100.0%
         │
         ▼
[Step 7: Test Inference] ──> predict.py (Visual inspection on test set)
         │
         ▼
[Step 8: Model Export] ──> best.pt ➔ best.onnx (Slimmed for edge deployment)
```

---

### Step 1: Raw Data Exploration & Spatial Analysis

1. **Source Data Analysis:**
   - Raw images: 44 total images with a resolution of `1280 x 720` pixels.
   - Annotations source: `dataset/labels_makesense.csv` containing 264 bounding box records.
   - Initial splits: 36 images in `dataset/train/` and 8 images in `dataset/test/`.

2. **Spatial Coordinate Analysis:**
   Analyzing bounding box distributions across all images revealed consistent spatial localization:
   - Component **S**: $X \approx [389, 407]$, $Y \approx [152, 240]$
   - Component **U**: $X \approx [623, 649]$, $Y \approx [183, 236]$
   - Component **C1**: $X \approx [254, 287]$, $Y \approx [395, 463]$
   - Component **I**: $X \approx [450, 469]$, $Y \approx [413, 461]$
   - Component **P**: $X \approx [612, 631]$, $Y \approx [475, 516]$
   - Component **C2**: $X \approx [757, 783]$, $Y \approx [414, 459]$

   > **Key Domain Finding:** Components are positioned in fixed jigs. Horizontal and vertical mirroring would swap asymmetrical components (e.g. flipping C1 on the left into the C2 location on the right). Therefore, training augmentations must disable flipping (`fliplr=0.0`, `flipud=0.0`).

---

### Step 2: Conversion to YOLO Format

A conversion script `convert_makesense_to_yolo.py` was executed to convert the raw MakeSense CSV data into the standard YOLO format:

1. **Coordinate Conversion Formula:**
   MakeSense provides: `[bbox_x, bbox_y, bbox_width, bbox_height]` (pixel coordinates relative to 1280x720).
   YOLO requires normalized center coordinates: `[class_id, x_center, y_center, width, height]` where all values are $\in [0, 1]$:

   $$\text{x\_center} = \frac{\text{bbox\_x} + \frac{\text{bbox\_width}}{2}}{\text{image\_width}}$$

   $$\text{y\_center} = \frac{\text{bbox\_y} + \frac{\text{bbox\_height}}{2}}{\text{image\_height}}$$

   $$\text{norm\_width} = \frac{\text{bbox\_width}}{\text{image\_width}}$$

   $$\text{norm\_height} = \frac{\text{bbox\_height}}{\text{image\_height}}$$

2. **Dataset Configuration (`data.yaml`):**
   ```yaml
   path: C:/Users/MAKERBRAINS/Downloads/Big Components Inspection/yolo_dataset
   train: images/train
   val: images/val

   names:
     0: C1A
     1: C1N
     2: C2A
     3: C2N
     4: IA
     5: IN
     6: PA
     7: PN
     8: SA
     9: SN
     10: UA
     11: UN
   ```

---

### Step 3: Dataset Integrity Verification

The dataset validation script `verify_dataset.py` checked all 44 images and label files:
- All 264 bounding boxes were verified to be strictly within $[0.0, 1.0]$.
- Class distribution across splits:

| Class | Train Set (36 images) | Val Set (8 images) | Total (44 images) |
| :--- | :---: | :---: | :---: |
| **C1A** | 25 | 5 | 30 |
| **C1N** | 11 | 3 | 14 |
| **C2A** | 25 | 5 | 30 |
| **C2N** | 11 | 3 | 14 |
| **IA** | 25 | 5 | 30 |
| **IN** | 11 | 3 | 14 |
| **PA** | 25 | 5 | 30 |
| **PN** | 11 | 3 | 14 |
| **SA** | 26 | 5 | 31 |
| **SN** | 10 | 3 | 13 |
| **UA** | 26 | 5 | 31 |
| **UN** | 10 | 3 | 13 |
| **Total Boxes** | **216** | **48** | **264** |

---

### Step 4: Model Architecture & Training Configuration

The project utilized **YOLO11 Nano (`yolo11n.pt`)**, the latest lightweight object detection architecture from Ultralytics.

#### Key Hyperparameters:
- **Architecture:** YOLO11 Nano (100 layers, 2.58M parameters, 6.4 GFLOPs)
- **Base Weights:** Pretrained ImageNet/COCO weights (`yolo11n.pt`)
- **Epochs:** 80
- **Image Size (`imgsz`):** 640
- **Batch Size:** 8
- **Device:** GPU:0 (NVIDIA RTX 5070 Ti)
- **Optimizer:** Auto (SGD/AdamW with Cosine LR schedule)
- **Patience:** 30 epochs
- **Data Augmentations:**
  - `fliplr = 0.0` (Disabled to protect component spatial alignment)
  - `flipud = 0.0` (Disabled to preserve board vertical orientation)
  - Color space jitter: Moderate HSV adjustments to simulate lighting shifts

---

### Step 5: Training Execution & Loss Convergence

Training was executed via:
```bash
python train.py --epochs 80 --batch 8 --device 0
```

#### Training Timeline:
- **Total Training Duration:** ~48 seconds across 80 epochs on RTX 5070 Ti.
- **Initial Loss (Epoch 1):** `box_loss: 1.748`, `cls_loss: 4.339`, `dfl_loss: 1.514`
- **Midway Loss (Epoch 40):** `box_loss: 0.612`, `cls_loss: 0.884`, `dfl_loss: 0.902`
- **Final Loss (Epoch 80):** `box_loss: 0.521`, `cls_loss: 0.675`, `dfl_loss: 0.848`
- Both training and validation losses converged smoothly without signs of overfitting.

---

### Step 6: Evaluation Results & Metrics

Evaluation on the independent validation set (8 images, 48 instances) produced high precision and recall:

#### Overall Performance Summary
- **Precision ($P$):** **97.94% (0.9794)**
- **Recall ($R$):** **100.00% (1.0000)**
- **mAP@0.5:** **99.50% (0.9950)**
- **mAP@0.5:0.95:** **89.60% (0.8960)**
- **Inference Speed:** **0.9 ms to 3.6 ms per image**

#### Per-Class Performance Breakdown

| Class Name | Target Component | Instances | Precision ($P$) | Recall ($R$) | mAP@0.5 | mAP@0.5:0.95 |
| :--- | :--- | :---: | :---: | :---: | :---: | :---: |
| **All Classes** | Overall Board | **48** | **0.979** | **1.000** | **0.995** | **0.896** |
| `C1A` | Capacitor 1 Present | 5 | 0.982 | 1.000 | 0.995 | 0.891 |
| `C1N` | Capacitor 1 Absent | 3 | 0.997 | 1.000 | 0.995 | 0.896 |
| `C2A` | Capacitor 2 Present | 5 | 0.980 | 1.000 | 0.995 | 0.915 |
| `C2N` | Capacitor 2 Absent | 3 | 0.972 | 1.000 | 0.995 | 0.907 |
| `IA` | Inductor Present | 5 | 0.989 | 1.000 | 0.995 | 0.915 |
| `IN` | Inductor Absent | 3 | 0.964 | 1.000 | 0.995 | 0.962 |
| `PA` | Power Port Present | 5 | 0.992 | 1.000 | 0.995 | 0.850 |
| `PN` | Power Port Absent | 3 | 0.966 | 1.000 | 0.995 | 0.863 |
| `SA` | Socket/Switch Present| 5 | 0.981 | 1.000 | 0.995 | 0.895 |
| `SN` | Socket/Switch Absent | 3 | 0.977 | 1.000 | 0.995 | 0.863 |
| `UA` | IC Unit Present | 5 | 0.976 | 1.000 | 0.995 | 0.899 |
| `UN` | IC Unit Absent | 3 | 0.976 | 1.000 | 0.995 | 0.895 |

---

### Step 7: Test Inference & Qualitative Verification

The inference pipeline `predict.py` was executed on all test images with a confidence threshold of 0.25:
```bash
python predict.py --weights runs/train/weights/best.pt --source yolo_dataset/images/val
```

#### Qualitative Findings:
1. **Fully Populated Boards (Images 1 to 5):**
   - Correctly identified all 6 components as Available (`C1A`, `C2A`, `IA`, `PA`, `SA`, `UA`) with high confidences ($0.88 - 0.99$).
   - Zero false detections and zero missed components.

2. **Unpopulated / Bare Boards (Images 6 to 8):**
   - Correctly identified all 6 components as Missing/Absent (`C1N`, `C2N`, `IN`, `PN`, `SN`, `UN`) with high confidences ($0.82 - 0.99$).
   - Clean separation between empty solder pads and mounted components.

Annotated output images are saved in `runs/predict_test/`.

---

### Step 8: Model Export for Production Deployment (ONNX)

To facilitate cross-platform deployment on edge devices, IPCs (Industrial PCs), embedded controllers, or microservices, the best trained model was exported to ONNX:

- **Primary ONNX Files:**
  - `runs/train/weights/best.onnx` (10.1 MB)
  - `weights/best.onnx` (10.1 MB)
- **ONNX Format Version:** Opset 17 / 18
- **Graph Optimization:** Slimmed and pruned using `onnxslim`
- **Model Tensor Architecture:**
  - **Input Tensor (`images`):** Shape `[1, 3, 640, 640]`, Data Type: `float32` (normalized RGB image tensor).
  - **Output Tensor (`output0`):** Shape `[1, 16, 8400]`, Data Type: `float32`:
    - Dim 0 (`1`): Batch size.
    - Dim 1 (`16`): 4 bounding box center/dimension coordinates $(x_c, y_c, w, h)$ + 12 component class confidence scores (`C1A`, `C1N`, `C2A`, `C2N`, `IA`, `IN`, `PA`, `PN`, `SA`, `SN`, `UA`, `UN`).
    - Dim 2 (`8400`): Candidate detection anchors distributed across the 3 feature pyramid scale levels $(80 \times 80 + 40 \times 40 + 20 \times 20 = 6400 + 1600 + 400 = 8400)$.
- **Verification & Benchmark:**
  - **Integrity Check:** Passed `onnx.checker.check_model()` with zero topology errors.
  - **ONNX Runtime Speed:** Benchmark latency of **~3.2 ms** per image on test verification.
- **Runtime Compatibility:**
  - ONNX Runtime (`onnxruntime` / `onnxruntime-gpu`)
  - OpenCV DNN (`cv2.dnn.readNetFromONNX`)
  - NVIDIA TensorRT (`trtexec --onnx=best.onnx --saveEngine=best.engine`)
  - Intel OpenVINO (`mo --input_model best.onnx`)

---

### Step 9: Representative Features for Edge Impulse & INT8 Quantization

When deploying custom models using the **Edge Impulse Bring Your Own Model (BYOM)** workflow, Edge Impulse provides an optional step: **"Upload representative features (Optional)"** to automatically quantize the ONNX model to INT8 precision for accelerated on-device execution on microcontrollers and embedded processors.

#### 1. Requirements for Edge Impulse Calibration Data
- **File Format:** Single NumPy `.npy` binary file.
- **Tensor Shape:** Must strictly match the input shape of the model across $N$ representative samples:
  $$\text{Shape} = (N, 3, 640, 640)$$
- **Data Type & Range:** `float32`, normalized to $[0.0, 1.0]$.
- **Channels Order:** RGB (matching YOLO training).
- **Preprocessing:** Identical letterboxing (preserving aspect ratio with padding) as used during inference.

#### 2. Generated Feature Files
Two calibration feature sets were generated via `generate_representative_features.py`:

| File Name | Sample Count | Array Dimensions | File Size | Description |
| :--- | :---: | :---: | :---: | :--- |
| **`representative_features_val.npy`** | 8 | `(8, 3, 640, 640)` | **39.3 MB** | Clean validation set (Recommended for standard Edge Impulse upload) |
| **`representative_features.npy`** | 44 | `(44, 3, 640, 640)` | **216.3 MB** | Comprehensive full dataset (Train + Val) for full-range calibration |
| **`weights/representative_features.npy`** | 8 | `(8, 3, 640, 640)` | **39.3 MB** | Copy alongside ONNX weights |

#### 3. How to Upload to Edge Impulse Studio
1. Open your project on **[Edge Impulse](https://studio.edgeimpulse.com/)**.
2. Navigate to **Dashboard** $\rightarrow$ **Upload your model** (under "Getting started").
3. In the model upload dialog:
   - Select and upload **`weights/best.onnx`** (or `runs/train/weights/best.onnx`).
4. In the **"Upload representative features (Optional)"** field:
   - Select and upload **`representative_features_val.npy`** (or `representative_features.npy`).
5. Click **Save model**. Edge Impulse will analyze the tensor ranges and automatically calibrate the INT8 quantization weights for your target hardware (e.g. Raspberry Pi, Jetson Nano, ESP32, STM32, Alif Semiconductor, Himax, etc.).

---

## 4. How to Reproduce & Use the Pipeline

### 1. Convert Dataset
```bash
python convert_makesense_to_yolo.py
```

### 2. Verify Dataset
```bash
python verify_dataset.py
```

### 3. Train Model
```bash
python train.py --epochs 80 --batch 8 --device 0
```

### 4. Run Live Webcam Inspection
```bash
# Using the custom dashboard inspection script (recommended):
python webcam_inspect.py --cam 0 --conf 0.4

# Or using the standard YOLO CLI command:
yolo predict model=runs/train/weights/best.pt source=0 show=True conf=0.4
```

### 5. Run Predictions on Static Images
```bash
python predict.py --weights runs/train/weights/best.pt --source <path_to_images>
```

### 6. Export to ONNX Format
```bash
# Using the dedicated exporter with graph verification and runtime test:
python export_onnx.py --weights runs/train/weights/best.pt --imgsz 640 --opset 17

# Or using the Ultralytics CLI:
yolo export model=runs/train/weights/best.pt format=onnx imgsz=640 opset=17
```

### 7. Run Inference with the ONNX Model
```bash
# Using YOLO with the ONNX weights:
yolo predict model=weights/best.onnx source=yolo_dataset/images/val conf=0.4

# Or with webcam:
python webcam_inspect.py --weights weights/best.onnx --cam 0 --conf 0.4
```

### 8. Generate Representative Features for Edge Impulse (.npy)
```bash
# Generate from validation set (39.3 MB, recommended for Edge Impulse upload):
python generate_representative_features.py --source val --output representative_features_val.npy

# Generate from full dataset (216.3 MB, all 44 images):
python generate_representative_features.py --source all --output representative_features.npy
```

---

## 5. Artifacts and Generated Files Directory

```
Big Components Inspection/
├── TRAINING_STEPS.md                      # Complete documentation of all training steps
├── data.yaml                              # YOLO dataset specification
├── convert_makesense_to_yolo.py           # MakeSense CSV to YOLO dataset converter
├── verify_dataset.py                      # Dataset validation and integrity script
├── train.py                               # Model training and validation script
├── predict.py                             # Production inference script
├── webcam_inspect.py                      # Live webcam inspection dashboard script
├── export_onnx.py                         # ONNX export and verification script
├── generate_representative_features.py    # Edge Impulse .npy feature generator
├── representative_features_val.npy        # Validation calibration features (39.3 MB)
├── representative_features.npy            # Full calibration features (216.3 MB)
├── yolo_dataset/                          # Prepared YOLO dataset
│   ├── images/ (train, val)
│   └── labels/ (train, val)
├── weights/
│   ├── best.onnx                          # Production ONNX model (10.1 MB)
│   └── representative_features.npy        # Calibration features copy (39.3 MB)
└── runs/
    ├── train/
    │   ├── weights/
    │   │   ├── best.pt                    # Best PyTorch model weights (5.5 MB)
    │   │   ├── last.pt                    # Final epoch weights
    │   │   └── best.onnx                  # Production ONNX model (10.1 MB)
    │   ├── results.csv                    # Epoch-by-epoch training logs
    │   ├── results.png                    # Training and validation loss curves
    │   ├── confusion_matrix.png           # Classification confusion matrix
    │   ├── BoxF1_curve.png                # F1-confidence trade-off curve
    │   └── BoxPR_curve.png                # Precision-Recall curve
    └── predict_test/                      # Visual prediction outputs on test set
```

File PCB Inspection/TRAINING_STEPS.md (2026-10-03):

# PCB Inspection - YOLO Vision Model Training Documentation

This document provides a comprehensive, step-by-step record of the training, validation, evaluation, and export of the YOLO object detection model for the **PCB Inspection** project.

---

## 1. Project Overview & Inspection Objective

### 1.1 Objective
The purpose of this project is Automated Optical Inspection (AOI) to detect and localize defects and surface issues on Printed Circuit Boards (PCBs). The model detects bounding boxes labeled as **`Issue`**.

### 1.2 Inspection Classes
- **Class Count:** 1 class (`Issue`)
- **Annotation Count:** 157 bounding boxes across 20 high-resolution images (`1280 x 720`).
- **Splits:** 16 training images (126 issues), 4 test images (31 issues).

---

## 2. Hardware and Software Environment
- **Operating System:** Windows 11
- **Python Version:** 3.14.6
- **Deep Learning Framework:** PyTorch 2.14.0+cu130
- **Computer Vision Framework:** Ultralytics YOLO v8.4.164
- **Accelerator / GPU:** NVIDIA GeForce RTX 5070 Ti (17 GB VRAM)
- **CUDA Support:** CUDA 13.0 Enabled

---

## 3. Step-by-Step Training Workflow

### Step 1: Dataset Exploration
- 20 total images in `train/` and `test/` folders.
- Labels parsed from `labels_makesense.csv` containing 157 bounding box instances.

### Step 2: YOLO Format Conversion
- Pixel coordinates `(bbox_x, bbox_y, bbox_width, bbox_height)` converted to normalized center coordinates `(x_center, y_center, width, height)`.
- Dataset structured into `yolo_dataset/images/` and `yolo_dataset/labels/` for `train` and `val`.
- Generated `data.yaml`.

### Step 3: Model Architecture & Training Optimization
- Architecture: **YOLO11s (`yolo11s.pt`)** with 9.4M parameters for improved feature resolution on fine defects.
- Hyperparameter Tuning for Micro-Defects:
  - `mosaic = 0.0`: Disabled to prevent cutting and tiling distortion of subtle defects.
  - `fliplr = 0.0`, `flipud = 0.0`: Preserves spatial orientation of the circuit layout.
  - `scale = 0.1`: Minimizes downscaling distortion of small solder/pad anomalies.
- Epochs: 100
- Batch size: 4
- Image size: 640
- Device: NVIDIA RTX 5070 Ti

### Step 4: Validation Performance
- **Precision ($P$):** **73.3% (0.733)**
- **Recall ($R$):** **62.1% (0.621)**
- **mAP@0.5:** **62.2% (0.622)**
- **mAP@0.5:0.95:** **25.5% (0.255)**

### Step 5: Test Inference
- Evaluated on test set images with visual defect bounding boxes saved to `runs/predict_test/`.

### Step 6: Model Export to ONNX
- Model exported to `weights/best.onnx` and `runs/train/weights/best.onnx`.
- Input tensor: `[1, 3, 640, 640]` (`float32`)
- Output tensor: `[1, 5, 8400]` (`float32`) -> 4 coordinates + 1 class score across 8400 anchor candidates.
- Slimmed and optimized with `onnxslim`.
- Target: Edge Impulse Bring Your Own Model (BYOM) deployment.

---

## 4. How to Run & Reproduce

### Run Live Webcam Inspection:
```bash
python webcam_inspect.py --weights weights/best.onnx --cam 0 --conf 0.30
```

### Run Batch Test Prediction:
```bash
yolo predict model=weights/best.onnx source=yolo_dataset/images/val conf=0.30
```

### Edge Impulse Labels:
```text
Issue
```

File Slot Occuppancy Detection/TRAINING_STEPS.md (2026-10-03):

# Slot Occuppancy Detection - YOLO Vision Model Training Documentation

This document provides a comprehensive, step-by-step record of the training, validation, evaluation, and export of the YOLO image classification model for the **Slot Occuppancy Detection** project.

---

## 1. Project Overview & Classification Objective

### 1.1 Objective
The purpose of this project is automated machine vision verification of slot occupancy in an electronic manufacturing or test fixture. The system classifies whether an inspection slot is:
1. **`Empty`** - No board present in the slot.
2. **`PCB`** - Bare, unpopulated Printed Circuit Board loaded.
3. **`PCBA`** - Populated Printed Circuit Board Assembly loaded with components.

### 1.2 Dataset Breakdown
- **Class Count:** 3 classes (`Empty`, `PCB`, `PCBA`)
- **Total Images:** 76 images
- **Train Split (61 images):**
  - `Empty`: 16 images
  - `PCB`: 21 images
  - `PCBA`: 24 images
- **Test / Validation Split (15 images):**
  - `Empty`: 4 images
  - `PCB`: 5 images
  - `PCBA`: 6 images

---

## 2. Hardware and Software Environment
- **Operating System:** Windows 11
- **Python Version:** 3.14.6
- **Deep Learning Framework:** PyTorch 2.14.0+cu130
- **Computer Vision Framework:** Ultralytics YOLO v8.4.164
- **Accelerator / GPU:** NVIDIA GeForce RTX 5070 Ti (17 GB VRAM)
- **CUDA Support:** CUDA 13.0 Enabled

---

## 3. Step-by-Step Training Workflow

### Step 1: Dataset Formatting & Organization
- Organized into standard YOLO classification structure:
  ```
  Slot Occuppancy Detection/
  ├── train/
  │   ├── Empty/
  │   ├── PCB/
  │   └── PCBA/
  └── test/
      ├── Empty/
      ├── PCB/
      └── PCBA/
  ```

### Step 2: Model Architecture
- Architecture: **YOLO11 Nano Classifier (`yolo11n-cls.pt`)**
- Pretrained backbone fine-tuned for high-speed edge classification.
- Image resolution: `224 x 224`
- Epochs: 50 (Early stopped at epoch 22 upon full convergence)
- Batch size: 8
- Device: NVIDIA RTX 5070 Ti

### Step 3: Evaluation Metrics
- **Top-1 Accuracy:** **1.0000 (100.00%)**
- **Top-5 Accuracy:** **1.0000 (100.00%)**
- **Inference Speed:** **~0.1 ms to 2.1 ms** per image on GPU.

### Step 4: Model Export to ONNX
- Model exported to `weights/best.onnx` and `runs/train/weights/best.onnx`.
- Input tensor: `[1, 3, 224, 224]` (`float32`)
- Output tensor: `[1, 3]` (`float32`) representing logits / class probabilities for `[Empty, PCB, PCBA]`.
- Slimmed and optimized with `onnxslim`.

---

## 4. How to Run & Reproduce

### Run Live Webcam Stream:
```bash
python webcam_inspect.py --weights weights/best.onnx --cam 0
```

### Run Batch Prediction:
```bash
yolo classify predict model=weights/best.onnx source=test
```

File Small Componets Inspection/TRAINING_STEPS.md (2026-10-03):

# Small Components Inspection - YOLO Vision Model Training Documentation

This document provides a comprehensive, step-by-step record of the training, validation, evaluation, and export of the YOLO object detection model for the **Small Components Inspection** project.

---

## 1. Project Overview & Inspection Objective

### 1.1 Objective
The purpose of this project is Automated Optical Inspection (AOI) of small passive and active electronic components (ceramic capacitors, inductors, chip resistors) on assembled circuit boards. The system detects whether each component is **Present / Available (`A`)** or **Absent / Missing (`N`)**.

### 1.2 Inspection Zones & Classes (26 Classes)
There are **13 physical component locations** inspected on each board:

| Component Code | Component Description | Present (`A`) | Absent (`N`) |
| :--- | :--- | :--- | :--- |
| **C1** | Ceramic Capacitor 1 | `C1A` | `C1N` |
| **C2** | Ceramic Capacitor 2 | `C2A` | `C2N` |
| **C3** | Ceramic Capacitor 3 | `C3A` | `C3N` |
| **C4** | Ceramic Capacitor 4 | `C4A` | `C4N` |
| **C5** | Ceramic Capacitor 5 | `C5A` | `C5N` |
| **C6** | Ceramic Capacitor 6 | `C6A` | `C6N` |
| **C7** | Ceramic Capacitor 7 | `C7A` | `C7N` |
| **L1** | SMD Inductor 1 | `L1A` | `L1N` |
| **L2** | SMD Inductor 2 | `L2A` | `L2N` |
| **R1** | Surface Resistor 1 | `R1A` | `R1N` |
| **R3** | Surface Resistor 3 | `R3A` | `R3N` |
| **R4** | Surface Resistor 4 | `R4A` | `R4N` |
| **R5** | Surface Resistor 5 | `R5A` | `R5N` |

---

## 2. Hardware and Software Environment
- **Operating System:** Windows 11
- **Python Version:** 3.14.6
- **Deep Learning Framework:** PyTorch 2.14.0+cu130
- **Computer Vision Framework:** Ultralytics YOLO v8.4.164
- **Accelerator / GPU:** NVIDIA GeForce RTX 5070 Ti (17 GB VRAM)
- **CUDA Support:** CUDA 13.0 Enabled

---

## 3. Step-by-Step Training Workflow

### Step 1: Data Cleansing & Integrity
1. Filtered out corrupted/degenerate bounding boxes (e.g. width=1, height=0 click artifact in original MakeSense CSV).
2. Cleaned out 4 incomplete images that only had 3 missing component tags without tagging the other 10 visible components, removing false-negative training penalties.
3. Clean dataset split: 41 training images (533 instances), 9 validation/test images (117 instances), all completely annotated across all 13 components.

### Step 2: YOLO Format Conversion
- Pixel coordinates transformed to normalized center coordinates $(x_c, y_c, w, h) \in [0.0, 1.0]$.
- Standardized directory layout under `yolo_dataset/`.
- Generated `data.yaml` defining all 26 classes.

### Step 3: Industrial AOI Model Training
- Architecture: **YOLO11 Nano (`yolo11n.pt`)** (2.58M parameters, 6.4 GFLOPs)
- Epochs: 100
- Batch size: 8
- Image size: 640
- Domain-specific spatial preservation: `mosaic = 0.0`, `fliplr = 0.0`, `flipud = 0.0` (preserves fixed circuit layout)
- Device: NVIDIA RTX 5070 Ti

### Step 4: Final Validation Performance
- **Overall Precision ($P$):** **89.69% (0.8969)**
- **Overall Recall ($R$):** **97.50% (0.9750)**
- **mAP@0.5:** **97.63% (0.9763)**
- **mAP@0.5:0.95:** **82.73% (0.8273)**
- **Class Highlights:** 24 out of 26 classes achieved **0.995 (99.5%) mAP@0.5** with **100% Recall**!

### Step 5: Test Inference
- Evaluated on test set images with predictions saved to `runs/predict_test/`.

### Step 6: Model Export to ONNX
- Exported to `weights/best.onnx` and `runs/train/weights/best.onnx`.
- Input tensor: `[1, 3, 640, 640]` (`float32`)
- Output tensor: `[1, 30, 8400]` (`float32`) -> 4 coordinates + 26 class scores across 8400 anchor candidates.
- Slimmed and optimized with `onnxslim`.
- Target: Edge Impulse Bring Your Own Model (BYOM) deployment.

---

## 4. How to Run & Reproduce

### Run Live Webcam Inspection:
```bash
python webcam_inspect.py --weights weights/best.onnx --cam 0 --conf 0.35
```

### Run Batch Prediction:
```bash
yolo predict model=weights/best.onnx source=yolo_dataset/images/val conf=0.35
```

### Edge Impulse Labels:
Paste into the Edge Impulse output labels field:
```text
C1A, C1N, C2A, C2N, C3A, C3N, C4A, C4N, C5A, C5N, C6A, C6N, C7A, C7N, L1A, L1N, L2A, L2N, R1A, R1N, R3A, R3N, R4A, R4N, R5A, R5N
```

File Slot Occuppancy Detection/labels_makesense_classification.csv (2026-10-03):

WIN_20260928_09_43_29_Pro.jpg | [PCBA]
WIN_20260928_09_43_47_Pro.jpg | [PCBA]
WIN_20260928_09_43_57_Pro.jpg | [PCBA]
WIN_20260928_09_43_59_Pro.jpg | [PCBA]
WIN_20260928_09_44_03_Pro.jpg | [PCBA]
WIN_20260928_09_44_04_Pro.jpg | [PCBA]
WIN_20260928_09_46_37_Pro.jpg | [PCBA]
WIN_20260928_09_46_38_Pro.jpg | [PCBA]
WIN_20260928_09_46_45_Pro.jpg | [PCBA]
WIN_20260928_09_46_46_Pro.jpg | [PCBA]
WIN_20260928_09_46_50_Pro.jpg | [PCBA]
WIN_20260928_09_46_51_Pro.jpg | [PCBA]
WIN_20260928_09_46_55_Pro.jpg | [PCBA]
WIN_20260928_09_46_56_Pro.jpg | [PCBA]
WIN_20260928_09_47_00_Pro.jpg | [PCBA]
WIN_20260928_09_47_01_Pro.jpg | [PCBA]
WIN_20260928_09_47_06_Pro.jpg | [PCBA]
WIN_20260928_09_47_07_Pro.jpg | [PCBA]
WIN_20260928_09_47_46_Pro.jpg | [PCBA]
WIN_20260928_09_47_47_Pro.jpg | [PCBA]
WIN_20260928_09_47_52_Pro.jpg | [PCBA]
WIN_20260928_09_47_53_Pro.jpg | [PCBA]
WIN_20260928_09_47_57_Pro.jpg | [PCBA]
WIN_20260928_09_47_58_Pro.jpg | [PCBA]
WIN_20260928_09_48_02_Pro (2).jpg | [PCBA]
WIN_20260928_09_48_02_Pro.jpg | [PCBA]
WIN_20260928_09_48_06_Pro.jpg | [PCBA]
WIN_20260928_09_48_07_Pro.jpg | [PCBA]
WIN_20260928_09_48_11_Pro.jpg | [PCBA]
WIN_20260928_09_48_12_Pro.jpg | [PCBA]
WIN_20260928_09_49_02_Pro.jpg | [Empty]
WIN_20260928_09_49_03_Pro.jpg | [Empty]
WIN_20260928_09_49_07_Pro.jpg | [Empty]
WIN_20260928_09_49_08_Pro.jpg | [Empty]
WIN_20260928_09_49_12_Pro.jpg | [Empty]
WIN_20260928_09_49_13_Pro.jpg | [Empty]
WIN_20260928_09_49_17_Pro (2).jpg | [Empty]
WIN_20260928_09_49_17_Pro.jpg | [Empty]
WIN_20260928_09_49_22_Pro (2).jpg | [Empty]
WIN_20260928_09_49_22_Pro.jpg | [Empty]
WIN_20260928_09_49_26_Pro.jpg | [Empty]
WIN_20260928_09_49_27_Pro.jpg | [Empty]
WIN_20260928_09_50_01_Pro.jpg | [Empty]
WIN_20260928_09_50_02_Pro.jpg | [Empty]
WIN_20260928_09_50_05_Pro.jpg | [Empty]
WIN_20260928_09_50_06_Pro.jpg | [Empty]
WIN_20260928_09_50_10_Pro (2).jpg | [Empty]
WIN_20260928_09_50_10_Pro.jpg | [Empty]
WIN_20260928_09_50_15_Pro (2).jpg | [Empty]
WIN_20260928_09_50_15_Pro.jpg | [Empty]
WIN_20260928_09_51_17_Pro.jpg | [PCB]
WIN_20260928_09_51_20_Pro.jpg | [PCB]
WIN_20260928_09_51_27_Pro.jpg | [PCB]
WIN_20260928_09_51_28_Pro.jpg | [PCB]
WIN_20260928_09_51_31_Pro.jpg | [PCB]
WIN_20260928_09_51_32_Pro.jpg | [PCB]
WIN_20260928_09_51_35_Pro.jpg | [PCB]
WIN_20260928_09_51_36_Pro.jpg | [PCB]
WIN_20260928_09_51_40_Pro.jpg | [PCB]
WIN_20260928_09_51_41_Pro.jpg | [PCB]
WIN_20260928_09_51_45_Pro.jpg | [PCB]
WIN_20260928_09_51_46_Pro.jpg | [PCB]
WIN_20260928_09_51_49_Pro.jpg | [PCB]
WIN_20260928_09_51_50_Pro.jpg | [PCB]
WIN_20260928_09_52_27_Pro.jpg | [PCB]
WIN_20260928_09_52_28_Pro.jpg | [PCB]
WIN_20260928_09_52_31_Pro.jpg | [PCB]
WIN_20260928_09_52_32_Pro.jpg | [PCB]
WIN_20260928_09_52_35_Pro.jpg | [PCB]
WIN_20260928_09_52_36_Pro.jpg | [PCB]
WIN_20260928_09_52_39_Pro.jpg | [PCB]
WIN_20260928_09_52_40_Pro.jpg | [PCB]
WIN_20260928_09_52_44_Pro (2).jpg | [PCB]
WIN_20260928_09_52_44_Pro.jpg | [PCB]
WIN_20260928_09_52_48_Pro (2).jpg | [PCB]
WIN_20260928_09_52_48_Pro.jpg | [PCB]

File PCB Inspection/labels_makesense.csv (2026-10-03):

label_name | bbox_x | bbox_y | bbox_width | bbox_height | image_name | image_width | image_height
Issue | 430 | 301 | 97 | 25 | WIN_20260929_14_14_23_Pro.jpg | 1280 | 720
Issue | 720 | 303 | 44 | 23 | WIN_20260929_14_14_23_Pro.jpg | 1280 | 720
Issue | 446 | 467 | 23 | 23 | WIN_20260929_14_14_23_Pro.jpg | 1280 | 720
Issue | 382 | 472 | 28 | 22 | WIN_20260929_14_14_23_Pro.jpg | 1280 | 720
Issue | 341 | 476 | 34 | 25 | WIN_20260929_14_14_23_Pro.jpg | 1280 | 720
Issue | 632 | 491 | 21 | 29 | WIN_20260929_14_14_23_Pro.jpg | 1280 | 720
Issue | 632 | 538 | 23 | 12 | WIN_20260929_14_14_23_Pro.jpg | 1280 | 720
Issue | 823 | 579 | 69 | 36 | WIN_20260929_14_14_23_Pro.jpg | 1280 | 720
Issue | 710 | 299 | 60 | 34 | WIN_20260929_14_14_26_Pro.jpg | 1280 | 720
Issue | 441 | 307 | 79 | 17 | WIN_20260929_14_14_26_Pro.jpg | 1280 | 720
Issue | 431 | 468 | 75 | 19 | WIN_20260929_14_14_26_Pro.jpg | 1280 | 720
Issue | 326 | 476 | 102 | 21 | WIN_20260929_14_14_26_Pro.jpg | 1280 | 720
Issue | 634 | 491 | 19 | 29 | WIN_20260929_14_14_26_Pro.jpg | 1280 | 720
Issue | 632 | 538 | 25 | 12 | WIN_20260929_14_14_26_Pro.jpg | 1280 | 720
Issue | 820 | 581 | 80 | 34 | WIN_20260929_14_14_26_Pro.jpg | 1280 | 720
Issue | 433 | 288 | 100 | 43 | WIN_20260929_14_14_33_Pro (2).jpg | 1280 | 720
Issue | 697 | 290 | 90 | 46 | WIN_20260929_14_14_33_Pro (2).jpg | 1280 | 720
Issue | 315 | 465 | 192 | 32 | WIN_20260929_14_14_33_Pro (2).jpg | 1280 | 720
Issue | 626 | 487 | 34 | 144 | WIN_20260929_14_14_33_Pro (2).jpg | 1280 | 720
Issue | 810 | 518 | 89 | 30 | WIN_20260929_14_14_33_Pro (2).jpg | 1280 | 720
Issue | 794 | 579 | 135 | 40 | WIN_20260929_14_14_33_Pro (2).jpg | 1280 | 720
Issue | 699 | 288 | 90 | 48 | WIN_20260929_14_14_33_Pro.jpg | 1280 | 720
Issue | 428 | 294 | 115 | 40 | WIN_20260929_14_14_33_Pro.jpg | 1280 | 720
Issue | 321 | 465 | 224 | 38 | WIN_20260929_14_14_33_Pro.jpg | 1280 | 720
Issue | 627 | 487 | 37 | 139 | WIN_20260929_14_14_33_Pro.jpg | 1280 | 720
Issue | 814 | 524 | 89 | 26 | WIN_20260929_14_14_33_Pro.jpg | 1280 | 720
Issue | 790 | 581 | 148 | 36 | WIN_20260929_14_14_33_Pro.jpg | 1280 | 720
Issue | 428 | 280 | 107 | 57 | WIN_20260929_14_14_36_Pro (2).jpg | 1280 | 720
Issue | 702 | 283 | 83 | 59 | WIN_20260929_14_14_36_Pro (2).jpg | 1280 | 720
Issue | 316 | 459 | 279 | 32 | WIN_20260929_14_14_36_Pro (2).jpg | 1280 | 720
Issue | 625 | 485 | 40 | 138 | WIN_20260929_14_14_36_Pro (2).jpg | 1280 | 720
Issue | 777 | 576 | 145 | 39 | WIN_20260929_14_14_36_Pro (2).jpg | 1280 | 720
Issue | 422 | 287 | 122 | 47 | WIN_20260929_14_14_36_Pro.jpg | 1280 | 720
Issue | 709 | 292 | 78 | 40 | WIN_20260929_14_14_36_Pro.jpg | 1280 | 720
Issue | 306 | 470 | 297 | 18 | WIN_20260929_14_14_36_Pro.jpg | 1280 | 720
Issue | 634 | 489 | 27 | 131 | WIN_20260929_14_14_36_Pro.jpg | 1280 | 720
Issue | 811 | 510 | 89 | 41 | WIN_20260929_14_14_36_Pro.jpg | 1280 | 720
Issue | 817 | 579 | 88 | 33 | WIN_20260929_14_14_36_Pro.jpg | 1280 | 720
Issue | 699 | 289 | 89 | 54 | WIN_20260929_14_14_40_Pro (2).jpg | 1280 | 720
Issue | 431 | 300 | 118 | 32 | WIN_20260929_14_14_40_Pro (2).jpg | 1280 | 720
Issue | 325 | 466 | 196 | 31 | WIN_20260929_14_14_40_Pro (2).jpg | 1280 | 720
Issue | 628 | 485 | 31 | 141 | WIN_20260929_14_14_40_Pro (2).jpg | 1280 | 720
Issue | 813 | 519 | 97 | 41 | WIN_20260929_14_14_40_Pro (2).jpg | 1280 | 720
Issue | 797 | 584 | 126 | 34 | WIN_20260929_14_14_40_Pro (2).jpg | 1280 | 720
Issue | 705 | 296 | 81 | 41 | WIN_20260929_14_14_40_Pro.jpg | 1280 | 720
Issue | 431 | 303 | 101 | 40 | WIN_20260929_14_14_40_Pro.jpg | 1280 | 720
Issue | 310 | 472 | 209 | 16 | WIN_20260929_14_14_40_Pro.jpg | 1280 | 720
Issue | 623 | 484 | 32 | 139 | WIN_20260929_14_14_40_Pro.jpg | 1280 | 720
Issue | 812 | 523 | 88 | 35 | WIN_20260929_14_14_40_Pro.jpg | 1280 | 720
Issue | 818 | 586 | 81 | 32 | WIN_20260929_14_14_40_Pro.jpg | 1280 | 720
Issue | 516 | 256 | 53 | 71 | WIN_20260929_14_15_03_Pro.jpg | 1280 | 720
Issue | 758 | 259 | 36 | 83 | WIN_20260929_14_15_03_Pro.jpg | 1280 | 720
Issue | 361 | 262 | 34 | 69 | WIN_20260929_14_15_03_Pro.jpg | 1280 | 720
Issue | 659 | 270 | 44 | 70 | WIN_20260929_14_15_03_Pro.jpg | 1280 | 720
Issue | 479 | 305 | 37 | 76 | WIN_20260929_14_15_03_Pro.jpg | 1280 | 720
Issue | 775 | 376 | 52 | 54 | WIN_20260929_14_15_03_Pro.jpg | 1280 | 720
Issue | 743 | 432 | 42 | 42 | WIN_20260929_14_15_03_Pro.jpg | 1280 | 720
Issue | 372 | 454 | 88 | 88 | WIN_20260929_14_15_03_Pro.jpg | 1280 | 720
Issue | 731 | 473 | 34 | 37 | WIN_20260929_14_15_03_Pro.jpg | 1280 | 720
Issue | 452 | 496 | 25 | 119 | WIN_20260929_14_15_03_Pro.jpg | 1280 | 720
Issue | 513 | 500 | 30 | 89 | WIN_20260929_14_15_03_Pro.jpg | 1280 | 720
Issue | 317 | 571 | 34 | 41 | WIN_20260929_14_15_03_Pro.jpg | 1280 | 720
Issue | 516 | 250 | 46 | 71 | WIN_20260929_14_15_04_Pro.jpg | 1280 | 720
Issue | 361 | 262 | 36 | 59 | WIN_20260929_14_15_04_Pro.jpg | 1280 | 720
Issue | 750 | 264 | 45 | 72 | WIN_20260929_14_15_04_Pro.jpg | 1280 | 720
Issue | 658 | 270 | 42 | 73 | WIN_20260929_14_15_04_Pro.jpg | 1280 | 720
Issue | 479 | 318 | 42 | 61 | WIN_20260929_14_15_04_Pro.jpg | 1280 | 720
Issue | 790 | 382 | 32 | 41 | WIN_20260929_14_15_04_Pro.jpg | 1280 | 720
Issue | 746 | 424 | 56 | 39 | WIN_20260929_14_15_04_Pro.jpg | 1280 | 720
Issue | 424 | 448 | 36 | 38 | WIN_20260929_14_15_04_Pro.jpg | 1280 | 720
Issue | 731 | 468 | 45 | 47 | WIN_20260929_14_15_04_Pro.jpg | 1280 | 720
Issue | 370 | 489 | 62 | 46 | WIN_20260929_14_15_04_Pro.jpg | 1280 | 720
Issue | 454 | 498 | 31 | 100 | WIN_20260929_14_15_04_Pro.jpg | 1280 | 720
Issue | 506 | 505 | 41 | 78 | WIN_20260929_14_15_04_Pro.jpg | 1280 | 720
Issue | 521 | 263 | 40 | 81 | WIN_20260929_14_15_06_Pro.jpg | 1280 | 720
Issue | 754 | 265 | 39 | 69 | WIN_20260929_14_15_06_Pro.jpg | 1280 | 720
Issue | 656 | 266 | 53 | 71 | WIN_20260929_14_15_06_Pro.jpg | 1280 | 720
Issue | 363 | 269 | 38 | 47 | WIN_20260929_14_15_06_Pro.jpg | 1280 | 720
Issue | 472 | 316 | 40 | 65 | WIN_20260929_14_15_06_Pro.jpg | 1280 | 720
Issue | 740 | 391 | 81 | 82 | WIN_20260929_14_15_06_Pro.jpg | 1280 | 720
Issue | 426 | 447 | 29 | 48 | WIN_20260929_14_15_06_Pro.jpg | 1280 | 720
Issue | 380 | 474 | 44 | 65 | WIN_20260929_14_15_06_Pro.jpg | 1280 | 720
Issue | 512 | 502 | 45 | 68 | WIN_20260929_14_15_06_Pro.jpg | 1280 | 720
Issue | 448 | 507 | 30 | 82 | WIN_20260929_14_15_06_Pro.jpg | 1280 | 720
Issue | 748 | 256 | 50 | 81 | WIN_20260929_14_15_07_Pro.jpg | 1280 | 720
Issue | 368 | 263 | 25 | 60 | WIN_20260929_14_15_07_Pro.jpg | 1280 | 720
Issue | 522 | 268 | 38 | 78 | WIN_20260929_14_15_07_Pro.jpg | 1280 | 720
Issue | 659 | 268 | 38 | 69 | WIN_20260929_14_15_07_Pro.jpg | 1280 | 720
Issue | 477 | 323 | 33 | 51 | WIN_20260929_14_15_07_Pro.jpg | 1280 | 720
Issue | 749 | 390 | 71 | 101 | WIN_20260929_14_15_07_Pro.jpg | 1280 | 720
Issue | 424 | 449 | 33 | 49 | WIN_20260929_14_15_07_Pro.jpg | 1280 | 720
Issue | 378 | 470 | 45 | 76 | WIN_20260929_14_15_07_Pro.jpg | 1280 | 720
Issue | 514 | 471 | 39 | 91 | WIN_20260929_14_15_07_Pro.jpg | 1280 | 720
Issue | 450 | 509 | 28 | 79 | WIN_20260929_14_15_07_Pro.jpg | 1280 | 720
Issue | 697 | 288 | 86 | 54 | WIN_20260929_14_15_50_Pro (2).jpg | 1280 | 720
Issue | 432 | 292 | 112 | 38 | WIN_20260929_14_15_50_Pro (2).jpg | 1280 | 720
Issue | 318 | 468 | 189 | 29 | WIN_20260929_14_15_50_Pro (2).jpg | 1280 | 720
Issue | 626 | 481 | 28 | 142 | WIN_20260929_14_15_50_Pro (2).jpg | 1280 | 720
Issue | 815 | 523 | 81 | 26 | WIN_20260929_14_15_50_Pro (2).jpg | 1280 | 720
Issue | 823 | 583 | 80 | 36 | WIN_20260929_14_15_50_Pro (2).jpg | 1280 | 720
Issue | 696 | 285 | 87 | 60 | WIN_20260929_14_15_50_Pro.jpg | 1280 | 720
Issue | 431 | 288 | 112 | 44 | WIN_20260929_14_15_50_Pro.jpg | 1280 | 720
Issue | 317 | 465 | 209 | 38 | WIN_20260929_14_15_50_Pro.jpg | 1280 | 720
Issue | 626 | 499 | 31 | 128 | WIN_20260929_14_15_50_Pro.jpg | 1280 | 720
Issue | 821 | 519 | 76 | 97 | WIN_20260929_14_15_50_Pro.jpg | 1280 | 720
Issue | 752 | 261 | 45 | 75 | WIN_20260929_14_16_09_Pro (2).jpg | 1280 | 720
Issue | 521 | 262 | 34 | 88 | WIN_20260929_14_16_09_Pro (2).jpg | 1280 | 720
Issue | 370 | 268 | 24 | 49 | WIN_20260929_14_16_09_Pro (2).jpg | 1280 | 720
Issue | 657 | 271 | 43 | 69 | WIN_20260929_14_16_09_Pro (2).jpg | 1280 | 720
Issue | 476 | 312 | 35 | 59 | WIN_20260929_14_16_09_Pro (2).jpg | 1280 | 720
Issue | 749 | 390 | 84 | 78 | WIN_20260929_14_16_09_Pro (2).jpg | 1280 | 720
Issue | 417 | 449 | 39 | 38 | WIN_20260929_14_16_09_Pro (2).jpg | 1280 | 720
Issue | 377 | 487 | 50 | 41 | WIN_20260929_14_16_09_Pro (2).jpg | 1280 | 720
Issue | 458 | 500 | 26 | 108 | WIN_20260929_14_16_09_Pro (2).jpg | 1280 | 720
Issue | 509 | 507 | 36 | 79 | WIN_20260929_14_16_09_Pro (2).jpg | 1280 | 720
Issue | 523 | 261 | 39 | 78 | WIN_20260929_14_16_09_Pro.jpg | 1280 | 720
Issue | 749 | 264 | 49 | 83 | WIN_20260929_14_16_09_Pro.jpg | 1280 | 720
Issue | 372 | 268 | 36 | 52 | WIN_20260929_14_16_09_Pro.jpg | 1280 | 720
Issue | 655 | 270 | 45 | 72 | WIN_20260929_14_16_09_Pro.jpg | 1280 | 720
Issue | 480 | 303 | 37 | 78 | WIN_20260929_14_16_09_Pro.jpg | 1280 | 720
Issue | 787 | 381 | 40 | 56 | WIN_20260929_14_16_09_Pro.jpg | 1280 | 720
Issue | 730 | 430 | 55 | 75 | WIN_20260929_14_16_09_Pro.jpg | 1280 | 720
Issue | 422 | 448 | 49 | 41 | WIN_20260929_14_16_09_Pro.jpg | 1280 | 720
Issue | 377 | 483 | 48 | 53 | WIN_20260929_14_16_09_Pro.jpg | 1280 | 720
Issue | 455 | 495 | 29 | 89 | WIN_20260929_14_16_09_Pro.jpg | 1280 | 720
Issue | 507 | 503 | 38 | 82 | WIN_20260929_14_16_09_Pro.jpg | 1280 | 720
Issue | 319 | 236 | 121 | 52 | WIN_20260929_14_16_27_Pro.jpg | 1280 | 720
Issue | 575 | 237 | 30 | 130 | WIN_20260929_14_16_27_Pro.jpg | 1280 | 720
Issue | 331 | 298 | 88 | 38 | WIN_20260929_14_16_27_Pro.jpg | 1280 | 720
Issue | 711 | 362 | 225 | 45 | WIN_20260929_14_16_27_Pro.jpg | 1280 | 720
Issue | 433 | 525 | 113 | 46 | WIN_20260929_14_16_27_Pro.jpg | 1280 | 720
Issue | 676 | 532 | 132 | 38 | WIN_20260929_14_16_27_Pro.jpg | 1280 | 720
Issue | 323 | 243 | 108 | 40 | WIN_20260929_14_16_28_Pro.jpg | 1280 | 720
Issue | 577 | 245 | 34 | 135 | WIN_20260929_14_16_28_Pro.jpg | 1280 | 720
Issue | 332 | 301 | 85 | 36 | WIN_20260929_14_16_28_Pro.jpg | 1280 | 720
Issue | 716 | 369 | 213 | 33 | WIN_20260929_14_16_28_Pro.jpg | 1280 | 720
Issue | 448 | 526 | 75 | 40 | WIN_20260929_14_16_28_Pro.jpg | 1280 | 720
Issue | 676 | 535 | 128 | 38 | WIN_20260929_14_16_28_Pro.jpg | 1280 | 720
Issue | 753 | 243 | 22 | 124 | WIN_20260929_14_16_44_Pro (2).jpg | 1280 | 720
Issue | 681 | 257 | 38 | 120 | WIN_20260929_14_16_44_Pro (2).jpg | 1280 | 720
Issue | 810 | 311 | 49 | 61 | WIN_20260929_14_16_44_Pro (2).jpg | 1280 | 720
Issue | 402 | 378 | 78 | 88 | WIN_20260929_14_16_44_Pro (2).jpg | 1280 | 720
Issue | 713 | 483 | 45 | 48 | WIN_20260929_14_16_44_Pro (2).jpg | 1280 | 720
Issue | 435 | 507 | 32 | 73 | WIN_20260929_14_16_44_Pro (2).jpg | 1280 | 720
Issue | 519 | 516 | 45 | 57 | WIN_20260929_14_16_44_Pro (2).jpg | 1280 | 720
Issue | 661 | 531 | 60 | 62 | WIN_20260929_14_16_44_Pro (2).jpg | 1280 | 720
Issue | 822 | 533 | 59 | 78 | WIN_20260929_14_16_44_Pro (2).jpg | 1280 | 720
Issue | 683 | 261 | 36 | 89 | WIN_20260929_14_16_44_Pro.jpg | 1280 | 720
Issue | 753 | 268 | 34 | 87 | WIN_20260929_14_16_44_Pro.jpg | 1280 | 720
Issue | 807 | 312 | 57 | 67 | WIN_20260929_14_16_44_Pro.jpg | 1280 | 720
Issue | 458 | 333 | 38 | 93 | WIN_20260929_14_16_44_Pro.jpg | 1280 | 720
Issue | 393 | 402 | 51 | 68 | WIN_20260929_14_16_44_Pro.jpg | 1280 | 720
Issue | 707 | 471 | 43 | 65 | WIN_20260929_14_16_44_Pro.jpg | 1280 | 720
Issue | 529 | 504 | 45 | 74 | WIN_20260929_14_16_44_Pro.jpg | 1280 | 720
Issue | 434 | 507 | 31 | 71 | WIN_20260929_14_16_44_Pro.jpg | 1280 | 720
Issue | 662 | 518 | 43 | 72 | WIN_20260929_14_16_44_Pro.jpg | 1280 | 720
Issue | 833 | 524 | 31 | 82 | WIN_20260929_14_16_44_Pro.jpg | 1280 | 720

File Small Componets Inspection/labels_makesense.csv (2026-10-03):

label_name | bbox_x | bbox_y | bbox_width | bbox_height | image_name | image_width | image_height
L2A | 565 | 248 | 70 | 116 | WIN_20260928_09_43_29_Pro.jpg | 1280 | 720
L1A | 300 | 254 | 79 | 83 | WIN_20260928_09_43_29_Pro.jpg | 1280 | 720
R5A | 869 | 324 | 74 | 62 | WIN_20260928_09_43_29_Pro.jpg | 1280 | 720
C1A | 359 | 362 | 110 | 42 | WIN_20260928_09_43_29_Pro.jpg | 1280 | 720
R1A | 469 | 363 | 76 | 40 | WIN_20260928_09_43_29_Pro.jpg | 1280 | 720
C2A | 553 | 365 | 116 | 35 | WIN_20260928_09_43_29_Pro.jpg | 1280 | 720
R4A | 870 | 393 | 72 | 66 | WIN_20260928_09_43_29_Pro.jpg | 1280 | 720
C5A | 654 | 397 | 128 | 36 | WIN_20260928_09_43_29_Pro.jpg | 1280 | 720
C3A | 386 | 405 | 87 | 45 | WIN_20260928_09_43_29_Pro.jpg | 1280 | 720
C4A | 552 | 408 | 80 | 59 | WIN_20260928_09_43_29_Pro.jpg | 1280 | 720
R3A | 470 | 410 | 71 | 59 | WIN_20260928_09_43_29_Pro.jpg | 1280 | 720
C6A | 657 | 436 | 124 | 32 | WIN_20260928_09_43_29_Pro.jpg | 1280 | 720
C7A | 659 | 471 | 119 | 34 | WIN_20260928_09_43_29_Pro.jpg | 1280 | 720
L2A | 567 | 250 | 71 | 114 | WIN_20260928_09_43_47_Pro.jpg | 1280 | 720
L1A | 295 | 253 | 93 | 90 | WIN_20260928_09_43_47_Pro.jpg | 1280 | 720
R5A | 869 | 323 | 76 | 64 | WIN_20260928_09_43_47_Pro.jpg | 1280 | 720
R1A | 468 | 360 | 80 | 43 | WIN_20260928_09_43_47_Pro.jpg | 1280 | 720
C2A | 553 | 367 | 116 | 34 | WIN_20260928_09_43_47_Pro.jpg | 1280 | 720
C1A | 356 | 368 | 107 | 34 | WIN_20260928_09_43_47_Pro.jpg | 1280 | 720
C5A | 659 | 396 | 119 | 34 | WIN_20260928_09_43_47_Pro.jpg | 1280 | 720
R4A | 869 | 396 | 73 | 60 | WIN_20260928_09_43_47_Pro.jpg | 1280 | 720
R3A | 472 | 404 | 72 | 70 | WIN_20260928_09_43_47_Pro.jpg | 1280 | 720
C3A | 385 | 405 | 87 | 47 | WIN_20260928_09_43_47_Pro.jpg | 1280 | 720
C4A | 553 | 407 | 79 | 62 | WIN_20260928_09_43_47_Pro.jpg | 1280 | 720
C6A | 661 | 436 | 117 | 32 | WIN_20260928_09_43_47_Pro.jpg | 1280 | 720
C7A | 661 | 471 | 116 | 36 | WIN_20260928_09_43_47_Pro.jpg | 1280 | 720
L1A | 309 | 219 | 80 | 91 | WIN_20260928_09_43_57_Pro.jpg | 1280 | 720
L2A | 565 | 224 | 72 | 116 | WIN_20260928_09_43_57_Pro.jpg | 1280 | 720
R5A | 867 | 305 | 76 | 71 | WIN_20260928_09_43_57_Pro.jpg | 1280 | 720
C1A | 358 | 334 | 105 | 36 | WIN_20260928_09_43_57_Pro.jpg | 1280 | 720
R1A | 467 | 334 | 78 | 43 | WIN_20260928_09_43_57_Pro.jpg | 1280 | 720
C2A | 551 | 341 | 119 | 34 | WIN_20260928_09_43_57_Pro.jpg | 1280 | 720
R4A | 614 | 357 | 1 | 0 | WIN_20260928_09_43_57_Pro.jpg | 1280 | 720
C3A | 382 | 371 | 85 | 45 | WIN_20260928_09_43_57_Pro.jpg | 1280 | 720
C5A | 655 | 375 | 123 | 32 | WIN_20260928_09_43_57_Pro.jpg | 1280 | 720
R4A | 865 | 380 | 73 | 62 | WIN_20260928_09_43_57_Pro.jpg | 1280 | 720
R3A | 462 | 381 | 75 | 62 | WIN_20260928_09_43_57_Pro.jpg | 1280 | 720
C4A | 543 | 382 | 87 | 64 | WIN_20260928_09_43_57_Pro.jpg | 1280 | 720
C6A | 656 | 415 | 126 | 33 | WIN_20260928_09_43_57_Pro.jpg | 1280 | 720
C7A | 655 | 452 | 120 | 35 | WIN_20260928_09_43_57_Pro.jpg | 1280 | 720
L1A | 307 | 218 | 80 | 93 | WIN_20260928_09_43_59_Pro.jpg | 1280 | 720
L2A | 567 | 223 | 68 | 114 | WIN_20260928_09_43_59_Pro.jpg | 1280 | 720
R5A | 869 | 310 | 75 | 62 | WIN_20260928_09_43_59_Pro.jpg | 1280 | 720
R1A | 467 | 333 | 76 | 49 | WIN_20260928_09_43_59_Pro.jpg | 1280 | 720
C1A | 356 | 334 | 108 | 34 | WIN_20260928_09_43_59_Pro.jpg | 1280 | 720
C2A | 548 | 344 | 124 | 32 | WIN_20260928_09_43_59_Pro.jpg | 1280 | 720
C3A | 385 | 374 | 86 | 41 | WIN_20260928_09_43_59_Pro.jpg | 1280 | 720
C5A | 653 | 375 | 125 | 34 | WIN_20260928_09_43_59_Pro.jpg | 1280 | 720
R4A | 866 | 376 | 75 | 65 | WIN_20260928_09_43_59_Pro.jpg | 1280 | 720
C4A | 543 | 379 | 85 | 67 | WIN_20260928_09_43_59_Pro.jpg | 1280 | 720
R3A | 467 | 380 | 71 | 66 | WIN_20260928_09_43_59_Pro.jpg | 1280 | 720
C6A | 654 | 413 | 119 | 36 | WIN_20260928_09_43_59_Pro.jpg | 1280 | 720
C7A | 653 | 450 | 124 | 36 | WIN_20260928_09_43_59_Pro.jpg | 1280 | 720
L2A | 562 | 246 | 67 | 117 | WIN_20260928_09_44_03_Pro.jpg | 1280 | 720
L1A | 300 | 250 | 82 | 92 | WIN_20260928_09_44_03_Pro.jpg | 1280 | 720
R5A | 857 | 323 | 82 | 62 | WIN_20260928_09_44_03_Pro.jpg | 1280 | 720
R1A | 466 | 359 | 77 | 44 | WIN_20260928_09_44_03_Pro.jpg | 1280 | 720
C2A | 542 | 360 | 119 | 44 | WIN_20260928_09_44_03_Pro.jpg | 1280 | 720
C1A | 354 | 364 | 108 | 39 | WIN_20260928_09_44_03_Pro.jpg | 1280 | 720
R4A | 860 | 385 | 78 | 74 | WIN_20260928_09_44_03_Pro.jpg | 1280 | 720
C5A | 652 | 393 | 115 | 36 | WIN_20260928_09_44_03_Pro.jpg | 1280 | 720
C3A | 383 | 402 | 83 | 44 | WIN_20260928_09_44_03_Pro.jpg | 1280 | 720
R3A | 465 | 402 | 76 | 69 | WIN_20260928_09_44_03_Pro.jpg | 1280 | 720
C4A | 545 | 404 | 85 | 64 | WIN_20260928_09_44_03_Pro.jpg | 1280 | 720
C6A | 653 | 432 | 115 | 34 | WIN_20260928_09_44_03_Pro.jpg | 1280 | 720
C7A | 652 | 467 | 119 | 44 | WIN_20260928_09_44_03_Pro.jpg | 1280 | 720
L2A | 562 | 246 | 68 | 118 | WIN_20260928_09_44_04_Pro.jpg | 1280 | 720
L1A | 299 | 251 | 84 | 90 | WIN_20260928_09_44_04_Pro.jpg | 1280 | 720
R5A | 862 | 323 | 75 | 67 | WIN_20260928_09_44_04_Pro.jpg | 1280 | 720
R1A | 463 | 358 | 78 | 47 | WIN_20260928_09_44_04_Pro.jpg | 1280 | 720
C1A | 355 | 361 | 111 | 40 | WIN_20260928_09_44_04_Pro.jpg | 1280 | 720
C2A | 547 | 366 | 115 | 34 | WIN_20260928_09_44_04_Pro.jpg | 1280 | 720
R4A | 862 | 391 | 74 | 64 | WIN_20260928_09_44_04_Pro.jpg | 1280 | 720
C5A | 654 | 393 | 115 | 36 | WIN_20260928_09_44_04_Pro.jpg | 1280 | 720
C3A | 377 | 399 | 92 | 47 | WIN_20260928_09_44_04_Pro.jpg | 1280 | 720
R3A | 464 | 400 | 79 | 71 | WIN_20260928_09_44_04_Pro.jpg | 1280 | 720
C4A | 547 | 407 | 82 | 61 | WIN_20260928_09_44_04_Pro.jpg | 1280 | 720
C6A | 656 | 431 | 113 | 35 | WIN_20260928_09_44_04_Pro.jpg | 1280 | 720
C7A | 654 | 470 | 117 | 39 | WIN_20260928_09_44_04_Pro.jpg | 1280 | 720
L2A | 564 | 252 | 71 | 113 | WIN_20260928_09_46_37_Pro.jpg | 1280 | 720
L1A | 302 | 253 | 84 | 91 | WIN_20260928_09_46_37_Pro.jpg | 1280 | 720
R5A | 867 | 323 | 78 | 64 | WIN_20260928_09_46_37_Pro.jpg | 1280 | 720
R1A | 470 | 364 | 78 | 41 | WIN_20260928_09_46_37_Pro.jpg | 1280 | 720
C1A | 356 | 369 | 111 | 36 | WIN_20260928_09_46_37_Pro.jpg | 1280 | 720
C2A | 549 | 370 | 117 | 34 | WIN_20260928_09_46_37_Pro.jpg | 1280 | 720
R4A | 865 | 389 | 82 | 65 | WIN_20260928_09_46_37_Pro.jpg | 1280 | 720
C5A | 656 | 391 | 126 | 39 | WIN_20260928_09_46_37_Pro.jpg | 1280 | 720
C4A | 546 | 404 | 88 | 68 | WIN_20260928_09_46_37_Pro.jpg | 1280 | 720
C3A | 389 | 405 | 84 | 43 | WIN_20260928_09_46_37_Pro.jpg | 1280 | 720
R3A | 468 | 409 | 73 | 65 | WIN_20260928_09_46_37_Pro.jpg | 1280 | 720
C6A | 654 | 432 | 122 | 40 | WIN_20260928_09_46_37_Pro.jpg | 1280 | 720
C7A | 656 | 474 | 122 | 35 | WIN_20260928_09_46_37_Pro.jpg | 1280 | 720
L2A | 565 | 250 | 72 | 115 | WIN_20260928_09_46_38_Pro.jpg | 1280 | 720
L1A | 299 | 253 | 87 | 93 | WIN_20260928_09_46_38_Pro.jpg | 1280 | 720
R5A | 870 | 323 | 75 | 65 | WIN_20260928_09_46_38_Pro.jpg | 1280 | 720
R1A | 469 | 364 | 78 | 45 | WIN_20260928_09_46_38_Pro.jpg | 1280 | 720
C1A | 358 | 365 | 111 | 39 | WIN_20260928_09_46_38_Pro.jpg | 1280 | 720
C2A | 550 | 367 | 117 | 35 | WIN_20260928_09_46_38_Pro.jpg | 1280 | 720
R4A | 870 | 392 | 80 | 63 | WIN_20260928_09_46_38_Pro.jpg | 1280 | 720
C5A | 654 | 395 | 125 | 38 | WIN_20260928_09_46_38_Pro.jpg | 1280 | 720
C4A | 545 | 404 | 89 | 65 | WIN_20260928_09_46_38_Pro.jpg | 1280 | 720
C3A | 389 | 406 | 84 | 46 | WIN_20260928_09_46_38_Pro.jpg | 1280 | 720
R3A | 470 | 410 | 73 | 65 | WIN_20260928_09_46_38_Pro.jpg | 1280 | 720
C6A | 656 | 437 | 125 | 31 | WIN_20260928_09_46_38_Pro.jpg | 1280 | 720
C7A | 656 | 472 | 120 | 38 | WIN_20260928_09_46_38_Pro.jpg | 1280 | 720
L1A | 304 | 219 | 83 | 95 | WIN_20260928_09_46_45_Pro.jpg | 1280 | 720
L2A | 564 | 224 | 71 | 119 | WIN_20260928_09_46_45_Pro.jpg | 1280 | 720
R5A | 867 | 310 | 78 | 64 | WIN_20260928_09_46_45_Pro.jpg | 1280 | 720
C1A | 356 | 336 | 110 | 38 | WIN_20260928_09_46_45_Pro.jpg | 1280 | 720
R1A | 472 | 339 | 71 | 42 | WIN_20260928_09_46_45_Pro.jpg | 1280 | 720
C2A | 547 | 345 | 123 | 38 | WIN_20260928_09_46_45_Pro.jpg | 1280 | 720
C5A | 654 | 376 | 123 | 34 | WIN_20260928_09_46_45_Pro.jpg | 1280 | 720
C3A | 387 | 378 | 82 | 47 | WIN_20260928_09_46_45_Pro.jpg | 1280 | 720
R4A | 867 | 378 | 78 | 67 | WIN_20260928_09_46_45_Pro.jpg | 1280 | 720
R3A | 464 | 383 | 76 | 67 | WIN_20260928_09_46_45_Pro.jpg | 1280 | 720
C4A | 545 | 383 | 82 | 67 | WIN_20260928_09_46_45_Pro.jpg | 1280 | 720
C6A | 650 | 416 | 127 | 33 | WIN_20260928_09_46_45_Pro.jpg | 1280 | 720
C7A | 653 | 454 | 121 | 34 | WIN_20260928_09_46_45_Pro.jpg | 1280 | 720
L1A | 305 | 218 | 84 | 95 | WIN_20260928_09_46_46_Pro.jpg | 1280 | 720
L2A | 565 | 224 | 68 | 119 | WIN_20260928_09_46_46_Pro.jpg | 1280 | 720
R5A | 864 | 308 | 80 | 65 | WIN_20260928_09_46_46_Pro.jpg | 1280 | 720
C1A | 356 | 336 | 109 | 43 | WIN_20260928_09_46_46_Pro.jpg | 1280 | 720
R1A | 468 | 336 | 76 | 43 | WIN_20260928_09_46_46_Pro.jpg | 1280 | 720
C2A | 548 | 345 | 117 | 34 | WIN_20260928_09_46_46_Pro.jpg | 1280 | 720
R4A | 867 | 375 | 76 | 68 | WIN_20260928_09_46_46_Pro.jpg | 1280 | 720
C3A | 384 | 377 | 84 | 42 | WIN_20260928_09_46_46_Pro.jpg | 1280 | 720
C5A | 656 | 377 | 119 | 34 | WIN_20260928_09_46_46_Pro.jpg | 1280 | 720
C4A | 545 | 380 | 86 | 64 | WIN_20260928_09_46_46_Pro.jpg | 1280 | 720
R3A | 466 | 381 | 77 | 68 | WIN_20260928_09_46_46_Pro.jpg | 1280 | 720
C6A | 650 | 417 | 123 | 32 | WIN_20260928_09_46_46_Pro.jpg | 1280 | 720
C7A | 651 | 453 | 122 | 38 | WIN_20260928_09_46_46_Pro.jpg | 1280 | 720
L1A | 302 | 242 | 80 | 93 | WIN_20260928_09_46_50_Pro.jpg | 1280 | 720
L2A | 562 | 242 | 69 | 117 | WIN_20260928_09_46_50_Pro.jpg | 1280 | 720
R5A | 865 | 316 | 76 | 66 | WIN_20260928_09_46_50_Pro.jpg | 1280 | 720
R1A | 469 | 353 | 73 | 47 | WIN_20260928_09_46_50_Pro.jpg | 1280 | 720
C1A | 357 | 358 | 107 | 39 | WIN_20260928_09_46_50_Pro.jpg | 1280 | 720
C3A | 547 | 360 | 122 | 34 | WIN_20260928_09_46_50_Pro.jpg | 1280 | 720
R4A | 865 | 386 | 78 | 60 | WIN_20260928_09_46_50_Pro.jpg | 1280 | 720
C5A | 652 | 389 | 119 | 35 | WIN_20260928_09_46_50_Pro.jpg | 1280 | 720
C4A | 545 | 395 | 86 | 70 | WIN_20260928_09_46_50_Pro.jpg | 1280 | 720
C2A | 389 | 397 | 78 | 41 | WIN_20260928_09_46_50_Pro.jpg | 1280 | 720
R3A | 464 | 402 | 80 | 65 | WIN_20260928_09_46_50_Pro.jpg | 1280 | 720
C6A | 652 | 430 | 124 | 30 | WIN_20260928_09_46_50_Pro.jpg | 1280 | 720
C7A | 652 | 462 | 124 | 45 | WIN_20260928_09_46_50_Pro.jpg | 1280 | 720
L2A | 562 | 241 | 73 | 116 | WIN_20260928_09_46_51_Pro.jpg | 1280 | 720
L1A | 299 | 244 | 87 | 89 | WIN_20260928_09_46_51_Pro.jpg | 1280 | 720
R5A | 867 | 320 | 73 | 63 | WIN_20260928_09_46_51_Pro.jpg | 1280 | 720
R1A | 468 | 352 | 80 | 45 | WIN_20260928_09_46_51_Pro.jpg | 1280 | 720
C1A | 352 | 357 | 115 | 40 | WIN_20260928_09_46_51_Pro.jpg | 1280 | 720
C2A | 548 | 362 | 117 | 31 | WIN_20260928_09_46_51_Pro.jpg | 1280 | 720
R4A | 866 | 384 | 78 | 64 | WIN_20260928_09_46_51_Pro.jpg | 1280 | 720
C5A | 650 | 388 | 124 | 34 | WIN_20260928_09_46_51_Pro.jpg | 1280 | 720
C4A | 545 | 396 | 85 | 67 | WIN_20260928_09_46_51_Pro.jpg | 1280 | 720
C3A | 382 | 399 | 87 | 43 | WIN_20260928_09_46_51_Pro.jpg | 1280 | 720
R3A | 468 | 401 | 72 | 68 | WIN_20260928_09_46_51_Pro.jpg | 1280 | 720
C6A | 652 | 427 | 122 | 37 | WIN_20260928_09_46_51_Pro.jpg | 1280 | 720
C7A | 654 | 465 | 121 | 41 | WIN_20260928_09_46_51_Pro.jpg | 1280 | 720
L1A | 304 | 226 | 84 | 91 | WIN_20260928_09_46_55_Pro.jpg | 1280 | 720
L2A | 567 | 229 | 67 | 117 | WIN_20260928_09_46_55_Pro.jpg | 1280 | 720
R5A | 865 | 314 | 78 | 64 | WIN_20260928_09_46_55_Pro.jpg | 1280 | 720
R1A | 470 | 336 | 76 | 48 | WIN_20260928_09_46_55_Pro.jpg | 1280 | 720
C1A | 358 | 340 | 108 | 38 | WIN_20260928_09_46_55_Pro.jpg | 1280 | 720
C2A | 549 | 350 | 117 | 32 | WIN_20260928_09_46_55_Pro.jpg | 1280 | 720
C5A | 652 | 379 | 121 | 34 | WIN_20260928_09_46_55_Pro.jpg | 1280 | 720
R4A | 866 | 379 | 73 | 65 | WIN_20260928_09_46_55_Pro.jpg | 1280 | 720
C3A | 381 | 381 | 87 | 43 | WIN_20260928_09_46_55_Pro.jpg | 1280 | 720
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

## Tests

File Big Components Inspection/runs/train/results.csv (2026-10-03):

epoch | time | train/box_loss | train/cls_loss | train/dfl_loss | metrics/precision(B) | metrics/recall(B) | metrics/mAP50(B) | metrics/mAP50-95(B) | val/box_loss | val/cls_loss | val/dfl_loss | lr/pg0 | lr/pg1 | lr/pg2
1 | 5.40952 | 1.74852 | 4.33962 | 1.51485 | 0.00086 | 0.05 | 0.00038 | 0.00022 | 1.95571 | 4.43285 | 1.88226 | 0.000166667 | 0.000166667 | 0.000166667
2 | 5.93696 | 1.76743 | 4.35224 | 1.50976 | 0.00069 | 0.03333 | 0.00037 | 0.00028 | 1.95065 | 4.41872 | 1.85867 | 0.000370359 | 0.000370359 | 0.000370359
3 | 6.48288 | 1.66714 | 4.3269 | 1.44451 | 0.00069 | 0.03333 | 0.00037 | 0.00028 | 1.95065 | 4.41872 | 1.85867 | 0.000568896 | 0.000568896 | 0.000568896
4 | 7.00551 | 1.51486 | 4.39621 | 1.45647 | 0.00693 | 0.26111 | 0.04807 | 0.00969 | 1.50162 | 4.57118 | 1.74647 | 0.000601797 | 0.000601797 | 0.000601797
5 | 7.53938 | 1.38352 | 4.3684 | 1.42864 | 0.00729 | 0.42222 | 0.11729 | 0.03637 | 0.85548 | 4.2567 | 1.01744 | 0.000594062 | 0.000594062 | 0.000594062
6 | 8.04233 | 1.05167 | 4.06019 | 1.08589 | 0.00729 | 0.42222 | 0.11729 | 0.03637 | 0.85548 | 4.2567 | 1.01744 | 0.000586328 | 0.000586328 | 0.000586328
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

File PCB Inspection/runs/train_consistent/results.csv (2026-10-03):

epoch | time | train/box_loss | train/cls_loss | train/dfl_loss | metrics/precision(B) | metrics/recall(B) | metrics/mAP50(B) | metrics/mAP50-95(B) | val/box_loss | val/cls_loss | val/dfl_loss | lr/pg0 | lr/pg1 | lr/pg2
1 | 3.48611 | 3.26024 | 7.2256 | 2.09662 | 0.00583 | 0.25 | 0.00196 | 0.0005 | 3.44229 | 6.29209 | 2.0273 | 0.0005 | 0.0005 | 0.0005
2 | 4.05614 | 3.28575 | 6.82096 | 2.04498 | 0.00583 | 0.25 | 0.00198 | 0.00049 | 3.44229 | 6.29209 | 2.0273 | 0.00115512 | 0.00115512 | 0.00115512
3 | 4.6199 | 3.43833 | 7.29009 | 2.21296 | 0.00583 | 0.25 | 0.00198 | 0.00049 | 3.44229 | 6.29209 | 2.0273 | 0.00179703 | 0.00179703 | 0.00179703
4 | 5.17516 | 3.42759 | 6.95538 | 2.19763 | 0.00583 | 0.25 | 0.00155 | 0.0002 | 3.43339 | 5.98127 | 2.08 | 0.0019406 | 0.0019406 | 0.0019406
5 | 5.73971 | 3.06951 | 7.06723 | 2.03456 | 0.00583 | 0.25 | 0.00155 | 0.0002 | 3.43339 | 5.98127 | 2.08 | 0.0019208 | 0.0019208 | 0.0019208
6 | 6.3062 | 3.28013 | 7.17895 | 2.10372 | 0.00583 | 0.25 | 0.00155 | 0.0002 | 3.43339 | 5.98127 | 2.08 | 0.001901 | 0.001901 | 0.001901
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

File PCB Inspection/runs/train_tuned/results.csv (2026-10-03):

epoch | time | train/box_loss | train/cls_loss | train/dfl_loss | metrics/precision(B) | metrics/recall(B) | metrics/mAP50(B) | metrics/mAP50-95(B) | val/box_loss | val/cls_loss | val/dfl_loss | lr/pg0 | lr/pg1 | lr/pg2
1 | 3.78374 | 3.28936 | 7.13014 | 2.10523 | 0.00583 | 0.24138 | 0.00196 | 0.00049 | 3.44901 | 6.30608 | 2.01931 | 0.0005 | 0.0005 | 0.0005
2 | 4.34398 | 3.31002 | 6.87184 | 2.06094 | 0.00583 | 0.24138 | 0.00198 | 0.00049 | 3.44901 | 6.30608 | 2.01931 | 0.00115512 | 0.00115512 | 0.00115512
3 | 4.92888 | 3.47336 | 7.27778 | 2.23274 | 0.00583 | 0.24138 | 0.00198 | 0.00049 | 3.44901 | 6.30608 | 2.01931 | 0.00179703 | 0.00179703 | 0.00179703
4 | 5.49419 | 3.43196 | 6.93754 | 2.19763 | 0.00583 | 0.24138 | 0.00155 | 0.00019 | 3.43506 | 5.99503 | 2.07109 | 0.0019406 | 0.0019406 | 0.0019406
5 | 6.0287 | 3.09576 | 7.06882 | 2.04109 | 0.00583 | 0.24138 | 0.00155 | 0.00019 | 3.43506 | 5.99503 | 2.07109 | 0.0019208 | 0.0019208 | 0.0019208
6 | 6.57832 | 3.28935 | 7.13757 | 2.10989 | 0.00583 | 0.24138 | 0.00155 | 0.00019 | 3.43506 | 5.99503 | 2.07109 | 0.001901 | 0.001901 | 0.001901
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

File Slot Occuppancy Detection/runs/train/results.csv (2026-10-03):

epoch | time | train/loss | metrics/accuracy_top1 | metrics/accuracy_top5 | val/loss | lr/pg0 | lr/pg1 | lr/pg2
1 | 4.89195 | 0.96828 | 0.86667 | 1 | 0.49665 | 0.000416792 | 0.000416792 | 0.000416792
2 | 5.36244 | 0.36586 | 1 | 1 | 0.08331 | 0.000875441 | 0.000875441 | 0.000875441
3 | 5.67346 | 0.14475 | 1 | 1 | 0.00841 | 0.00131523 | 0.00131523 | 0.00131523
4 | 5.98958 | 0.05348 | 1 | 1 | 0.00116 | 0.00134412 | 0.00134412 | 0.00134412
5 | 6.33275 | 0.07863 | 1 | 1 | 8e-05 | 0.00131582 | 0.00131582 | 0.00131582
6 | 6.65417 | 0.02947 | 1 | 1 | 3e-05 | 0.00128753 | 0.00128753 | 0.00128753
7 | 6.97881 | 0.16546 | 1 | 1 | 2e-05 | 0.00125923 | 0.00125923 | 0.00125923
8 | 7.30789 | 0.01465 | 1 | 1 | 5e-05 | 0.00123094 | 0.00123094 | 0.00123094
9 | 7.6274 | 0.27987 | 1 | 1 | 3e-05 | 0.00120265 | 0.00120265 | 0.00120265
10 | 7.93889 | 0.02958 | 1 | 1 | 4e-05 | 0.00117435 | 0.00117435 | 0.00117435
11 | 8.2686 | 0.22256 | 1 | 1 | 6e-05 | 0.00114606 | 0.00114606 | 0.00114606
12 | 8.59235 | 0.02216 | 1 | 1 | 7e-05 | 0.00111776 | 0.00111776 | 0.00111776
13 | 8.90404 | 0.00705 | 1 | 1 | 0.0001 | 0.00108947 | 0.00108947 | 0.00108947
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

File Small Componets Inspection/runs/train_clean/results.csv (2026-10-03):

epoch | time | train/box_loss | train/cls_loss | train/dfl_loss | metrics/precision(B) | metrics/recall(B) | metrics/mAP50(B) | metrics/mAP50-95(B) | val/box_loss | val/cls_loss | val/dfl_loss | lr/pg0 | lr/pg1 | lr/pg2
1 | 4.17979 | 3.17574 | 5.43863 | 2.21685 | 0 | 0 | 0 | 0 | 3.47991 | 5.32715 | 2.32128 | 9.25e-05 | 9.25e-05 | 9.25e-05
2 | 4.64987 | 3.15118 | 5.46136 | 2.20898 | 0 | 0 | 0 | 0 | 3.4874 | 5.22097 | 2.22628 | 0.000201485 | 0.000201485 | 0.000201485
3 | 5.13302 | 3.16262 | 5.47407 | 2.13835 | 0 | 0 | 0 | 0 | 3.4874 | 5.22097 | 2.22628 | 0.000308273 | 0.000308273 | 0.000308273
4 | 5.60483 | 2.76554 | 5.36062 | 1.86673 | 0 | 0 | 0 | 0 | 2.08801 | 5.27212 | 1.49239 | 0.00032311 | 0.00032311 | 0.00032311
5 | 6.07697 | 2.16297 | 5.15796 | 1.48752 | 0 | 0 | 0 | 0 | 1.66112 | 5.11973 | 1.1715 | 0.000319813 | 0.000319813 | 0.000319813
6 | 6.55533 | 1.79778 | 4.93788 | 1.20426 | 0 | 0 | 0 | 0 | 1.24826 | 4.93957 | 0.98191 | 0.000316517 | 0.000316517 | 0.000316517
7 | 7.03929 | 1.36013 | 4.77481 | 1.0778 | 0 | 0 | 0 | 0 | 1.24826 | 4.93957 | 0.98191 | 0.00031322 | 0.00031322 | 0.00031322
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

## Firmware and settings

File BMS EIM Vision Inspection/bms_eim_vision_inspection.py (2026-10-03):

#!/usr/bin/env python3
"""
BMS Vision Inspection — Pure Edge Impulse (.eim) Photo-Level AOI System
======================================================================
Engineered for Arduino UNO Q (Qualcomm QRB2210 Linux MPU + STM32U585 Zephyr MCU)
& Edge SBCs (Debian / Linux / Cross-Platform).

Key Architectural Specifications:
  1. Pure .EIM Execution (ZERO ONNX RUNTIME):
     - Directly communicates with compiled Edge Impulse .eim binaries via Unix domain socket IPC
     - High-speed POSIX Shared Memory (SHM) zero-copy tensor streaming
  2. Fit-Longest Aspect-Ratio Preserving Preprocessing:
     - Scales longest axis to model input dimensions and pads with 0
     - Configured for unquantized float32 Edge Impulse models
     - Guarantees 100% field-of-view retention for peripheral SMD passives and edge connectors
  3. Arduino UNO Q Dual-Domain Architecture:
     - Pure Python zero-dependency Unix domain socket client connecting to /var/run/arduino-router.sock
     - Full fallback for arduino.app_utils.Bridge, UART Serial, or Virtual Simulation
  4. Photo-Level 6-Slot Turntable Inspection:
     - Continuous camera worker drains V4L2/DirectShow buffers for zero queue lag
     - Distance-adaptive servo travel and settle delay eliminates motion blur
  5. Minimal Lightweight Runtime:
     - Strictly uses: Flask, OpenCV, NumPy (no onnxruntime).
"""

import os
import sys
import time
import json
import glob
import math
import socket
import shutil
import signal
import tempfile
import argparse
import threading
import subprocess
import concurrent.futures
from pathlib import Path

import cv2
import numpy as np
from flask import Flask, Response, render_template_string, jsonify, request, send_file, redirect

# Verify OpenCV is a real functional installation (not the fake/empty PyPI 'cv2' package)
if not hasattr(cv2, "VideoCapture") or not hasattr(cv2, "cvtColor"):
    print("\n" + "=" * 72)
    print("  [CRITICAL ERROR] The installed 'cv2' module has no VideoCapture/cvtColor!")
    print("  This occurs when the dummy placeholder PyPI package 'cv2' was installed")
    print("  instead of 'opencv-python-headless', or OpenCV was corrupted during install.")
    print("  Fix it by running these commands in your active virtualenv (.venv):")
    print("      pip uninstall -y cv2 opencv-python opencv-python-headless")
    print("      pip install --no-cache-dir opencv-python-headless")
    print("=" * 72 + "\n")
    sys.exit(1)

# POSIX Shared Memory for zero-copy EIM tensor feeds
try:
    from multiprocessing import shared_memory
    HAS_SHM = True
except ImportError:
    shared_memory = None
    HAS_SHM = False

# Arduino UNO Q app_utils
try:
    from arduino.app_utils import Bridge
    HAS_APP_BRIDGE = True
except ImportError:
    Bridge = None
    HAS_APP_BRIDGE = False

# PySerial
try:
    import serial
    import serial.tools.list_ports
except ImportError:
    serial = None

# ── DIRECTORIES & MODEL BINDINGS ─────────────────────────────────────────────
BASE_DIR      = Path(__file__).resolve().parent
MODELS_DIR    = BASE_DIR / "models"
SNAPSHOT_DIR  = BASE_DIR / "snapshots"
SNAPSHOT_DIR.mkdir(parents=True, exist_ok=True)

# Direct paths to Edge Impulse .eim models
SLOT_MODEL_P  = MODELS_DIR / "slot-occupancy.eim"
BIG_MODEL_P   = MODELS_DIR / "big-components-inspection.eim"
SMALL_MODEL_P = MODELS_DIR / "small-components-inspection.eim"
PCB_MODEL_P   = MODELS_DIR / "pcb-inspection.eim"

# ── HARDWARE CONSTANTS ───────────────────────────────────────────────────────
SERVO_POSITIONS   = [500, 930, 1360, 1790, 2220, 2650]  # Pulse widths for slots 1-6
AUTO_IDLE_TIMEOUT = 10.0                               # Revert to Auto Loop after 10s idle

# ── COMPONENT DEFINITIONS & LABELS (PER TRAINING DATASETS) ───────────────────
# Big Components: 6 Physical Locations, 12 Classes (A = Available/Present, N = Absent/Missing)
BIG_CLASSES = [
    "C1A", "C1N", "C2A", "C2N", "IA", "IN", "PA", "PN", "SA", "SN", "UA", "UN"
]
BIG_COMPONENTS = [
    ("S",  "Switch / Socket"),
    ("U",  "IC / USB Unit"),
    ("C1", "Capacitor 1"),
    ("I",  "Inductor"),
    ("P",  "Power IC"),
    ("C2", "Capacitor 2"),
]

# Small Components: 13 Physical Locations, 26 Classes
SMALL_CLASSES = [
    "C1A", "C1N", "C2A", "C2N", "C3A", "C3N", "C4A", "C4N",
    "C5A", "C5N", "C6A", "C6N", "C7A", "C7N", "L1A", "L1N",
    "L2A", "L2N", "R1A", "R1N", "R3A", "R3N", "R4A", "R4N",
    "R5A", "R5N",
]
SMALL_COMPONENTS = [
    ("C1", "Capacitor 1"),
    ("C2", "Capacitor 2"),
    ("C3", "Capacitor 3"),
    ("C4", "Capacitor 4"),
    ("C5", "Capacitor 5"),
    ("C6", "Capacitor 6"),
    ("C7", "Capacitor 7"),
    ("L1", "Inductor / LED 1"),
    ("L2", "Inductor / LED 2"),
    ("R1", "Resistor 1"),
    ("R3", "Resistor 3"),
    ("R4", "Resistor 4"),
    ("R5", "Resistor 5"),
]

# Fixture Occupancy Classes
SLOT_CLASSES  = ["Empty", "PCB", "PCBA"]

# Bare PCB Defect Classes
PCB_CLASSES   = ["Issue"]

# Visual Overlays Colors (BGR)
COLOR_AVAILABLE   = (46, 170, 40)     # Clean green (PASS / Present)
COLOR_MISSING     = (35, 45, 230)     # Vivid red (FAIL / Missing)
COLOR_WARN_AMBER  = (10, 150, 240)    # Amber / warning
COLOR_ROI_CYAN    = (210, 150, 30)    # Cyan / teal for reticle

FONT    = getattr(cv2, "FONT_HERSHEY_DUPLEX", 2)
FONTS   = getattr(cv2, "FONT_HERSHEY_SIMPLEX", 0)
LINE_AA = getattr(cv2, "LINE_AA", 16)


# ── ARDUINO UNO Q DIRECT ROUTER BRIDGE CLIENT ────────────────────────────────
class UnoQBridgeClient:
    """
    Direct zero-dependency Unix domain socket client for Arduino UNO Q's arduino-router.
    Communicates via MessagePack-RPC over /var/run/arduino-router.sock.
    Pure Python standard library implementation.
    """
    SOCK_PATH = "/var/run/arduino-router.sock"

    def __init__(self):
        self.sock = None
        self.is_connected = False
        self.lock = threading.Lock()
        self.connect()

    def _pack_str(self, s):
        b = str(s).encode("utf-8")
        l = len(b)
        if l <= 31:
            return bytes([0xa0 | l]) + b
        elif l <= 0xFF:
            return b"\xd9" + bytes([l]) + b
        return b"\xda" + l.to_bytes(2, "big") + b

    def _pack_notify(self, method, args):
        m_bytes = self._pack_str(method)
        arg_bytes = bytes([0x90 | len(args)])
        for a in args:
            if isinstance(a, int):
                arg_bytes += bytes([a]) if 0 <= a <= 127 else (b"\xcc" + bytes([a]))
            elif isinstance(a, str):
                arg_bytes += self._pack_str(a)
        return b"\x93\x02" + m_bytes + arg_bytes

    def connect(self):
        with self.lock:
            if not os.path.exists(self.SOCK_PATH):
                self.is_connected = False
                return False
            try:
                s = socket.socket(socket.AF_UNIX, socket.SOCK_STREAM)
                s.settimeout(1.0)
                s.connect(self.SOCK_PATH)
                self.sock = s
                self.is_connected = True
                return True
            except Exception:
                self.sock = None
                self.is_connected = False
                return False

    def notify(self, method, *args):
        pkt = self._pack_notify(method, args)
        with self.lock:
            if not self.is_connected or self.sock is None:
                if not self.connect():
                    return False
            try:
                self.sock.sendall(pkt)
                return True
            except Exception:
                self.is_connected = False
                self.sock = None
                return False

    def close(self):
        with self.lock:
            if self.sock:
                try:
                    self.sock.close()
                except Exception:
                    pass
            self.sock = None
            self.is_connected = False


# ── ARDUINO HARDWARE INTERFACE ───────────────────────────────────────────────
class ArduinoHardwareController:
    """
    Unified Hardware Controller supporting:
      1. Arduino UNO Q Direct Unix Socket Bridge (/var/run/arduino-router.sock)
      2. Arduino UNO Q app_utils.Bridge RPC
      3. UART Serial Interface (USB / External Arduino)
      4. Virtual Simulation Fallback
    """
    def __init__(self, port="auto", baudrate=115200):
        self.port = port
        self.baudrate = baudrate
        self.ser = None
        self.bridge_client = UnoQBridgeClient()
        self.backend = "sim"
        self.is_connected = False
        self.current_led = "GREEN"
        self.current_slot = 1
        self.lock = threading.Lock()
        self._connect()

    @staticmethod
    def list_available_ports():
        ports = []
        if os.path.exists("/var/run/arduino-router.sock") or HAS_APP_BRIDGE:
            ports.append({"device": "bridge", "description": "Arduino UNO Q Internal Bridge"})

        if serial is not None:
            try:
                for p in serial.tools.list_ports.comports():
                    desc = (p.description or p.device).strip()
                    hwid = (p.hwid or "").strip()
                    if "bluetooth" in desc.lower() or "bthenum" in hwid.lower():
                        continue
                    ports.append({"device": p.device, "description": desc})
            except Exception:
                pass

        if sys.platform.startswith("linux"):
            for p in glob.glob("/dev/ttyRPMSG*") + glob.glob("/dev/ttyHS*") + glob.glob("/dev/ttyMSM*") + glob.glob("/dev/ttyACM*") + glob.glob("/dev/ttyUSB*"):
                ports.append({"device": p, "description": p})

        return ports

    def _find_candidate_ports(self):
        candidates = []
        if serial is not None:
            try:
                for p in serial.tools.list_ports.comports():
                    desc = (p.description or "").lower()
                    hwid = (p.hwid or "").lower()
                    if "bluetooth" in desc or "bthenum" in hwid:
                        continue
                    candidates.append(p.device)
            except Exception:
                pass

        if sys.platform.startswith("linux"):
            for p in ["/dev/ttyACM0", "/dev/ttyACM1", "/dev/ttyUSB0", "/dev/ttyUSB1", "/dev/ttyHS0", "/dev/ttyRPMSG0"]:
                if os.path.exists(p) and p not in candidates:
                    candidates.append(p)

        return candidates

    def connect_to_port(self, port="auto", baudrate=115200):
        with self.lock:
            if self.ser:
                try:
                    self.ser.close()
                except Exception:
                    pass
                self.ser = None

            self.port = port
            self.baudrate = baudrate
            self.is_connected = False

            # Check UNO Q internal bridge
            if port in ("auto", "bridge") and (self.bridge_client.is_connected or os.path.exists("/var/run/arduino-router.sock") or HAS_APP_BRIDGE):
                if not self.bridge_client.is_connected:
                    self.bridge_client.connect()
                if self.bridge_client.is_connected or HAS_APP_BRIDGE:
                    self.backend = "bridge"
                    self.is_connected = True
                    print(f"  [Hardware] Connected via Arduino UNO Q Internal Bridge (/var/run/arduino-router.sock)")
                    return True, "Connected via Arduino UNO Q Internal Bridge"

            if serial is None:
                self.backend = "sim"
                self.is_connected = False
                return False, "pyserial not installed (running simulation)"

            candidates = [port] if (port != "auto" and port != "bridge") else self._find_candidate_ports()

            for cand in candidates:
                try:
                    print(f"  [Hardware] Attempting serial connection to {cand} @ {baudrate}...")
                    s = serial.Serial(cand, baudrate, timeout=1.0, write_timeout=1.0)
                    time.sleep(1.8)
                    self.ser = s
                    self.backend = "serial"
                    self.is_connected = True
                    self.port = cand
                    print(f"  [Hardware] Successfully connected via Serial: {cand}")
                    return True, f"Connected to {cand}"
                except Exception as e:
                    print(f"  [Hardware] Serial open failed on {cand}: {e}")

            self.backend = "sim"
            self.is_connected = False
            return False, f"Could not open {port}"

    def _connect(self):
        if self.port == "none":
            print("  [Hardware] Hardware link disabled. Running in Virtual Simulation mode.")
            return

        ok, msg = self.connect_to_port(self.port, self.baudrate)
        if not ok:
            print(f"  [Hardware] {msg}")

    def move_to_slot(self, slot_id):
        """Commands servo to rotate to target slot (1-6). Distance-adaptive timing prevents motion blur."""
        slot_id = max(1, min(6, int(slot_id)))
        prev_slot = self.current_slot
        dist = abs(slot_id - prev_slot)
        self.current_slot = slot_id

        # Adaptive travel time for rotary table inertia
        if dist <= 0:
            travel_time = 0.40
        elif dist == 1:
            travel_time = 0.82
        else:
            travel_time = 0.82 + (dist - 1) * 0.28  # dist 5 => ~1.94s

        with self.lock:
            if self.bridge_client.is_connected or self.backend == "bridge":
                self.bridge_client.notify("move_servo", slot_id)
                if HAS_APP_BRIDGE:
                    try:
                        Bridge.notify("move_servo", int(slot_id))
                    except Exception:
                        pass
                time.sleep(travel_time)
            elif self.backend == "serial" and self.ser:
                try:
                    self.ser.reset_input_buffer()
                    cmd = f"{slot_id}\n".encode("utf-8")
                    self.ser.write(cmd)
                    self.ser.flush()
                except Exception as e:
                    print(f"[Hardware Warning] Serial write error: {e}")
                time.sleep(travel_time)
            else:
                time.sleep(travel_time)

    def set_led(self, state):
        """Sets WS2812B NeoPixel indicator: Strictly 'PASS' (Green) or 'FAIL' (Red)."""
        state = state.upper()
        if state in ("PASS", "GREEN", "P"):
            self.current_led = "PASS"
            cmd_char = 'P'
            bridge_state = "PASS"
        else:
            self.current_led = "FAIL"
            cmd_char = 'F'
            bridge_state = "FAIL"

        with self.lock:
            if self.bridge_client.is_connected or self.backend == "bridge":
                self.bridge_client.notify("set_led", bridge_state)
                if HAS_APP_BRIDGE:
                    try:
                        Bridge.notify("set_led", bridge_state)
                    except Exception:
                        pass
            elif self.backend == "serial" and self.ser:
                try:
                    self.ser.write(f"{cmd_char}\n".encode("utf-8"))
                    self.ser.flush()
                except Exception:
                    pass

    def close(self):
        with self.lock:
            self.bridge_client.close()
            if self.ser:
                try:
                    self.ser.close()
                except Exception:
                    pass
            self.ser = None
            self.is_connected = False
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

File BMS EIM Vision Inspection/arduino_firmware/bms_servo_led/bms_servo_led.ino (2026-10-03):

/**
 * BMS Vision Inspection — Rotary Table Servo & WS2812B Controller
 * ==============================================================
 * Compatible with:
 *   - Arduino UNO Q (Qualcomm QRB2210 Linux MPU + STM32U585 Zephyr MCU via
 * Bridge RPC)
 *   - Standard Arduino boards (UNO, Nano, Mega via Serial UART)
 *
 * Hardware Wiring:
 *   - Servo Motor Signal: Pin 9 (PWM)
 *   - WS2812B NeoPixel Data: Pin 8 (RGB LED)
 *
 * Rotary Positions (Microseconds):
 *   Slot 1:  500 us
 *   Slot 2:  930 us
 *   Slot 3: 1360 us
 *   Slot 4: 1790 us
 *   Slot 5: 2220 us
 *   Slot 6: 2650 us
 *
 * LED Indications:
 *   - Motor Moving / Positioning: ORANGE (RGB: 255, 120, 0)
 *   - Inspection Result PASS:    GREEN  (RGB: 0, 255, 0)
 *   - Inspection Result FAIL:    RED    (RGB: 255, 0, 0)
 *   - Empty Slot / Standby:      AMBER  (RGB: 160, 90, 0)
 *
 * Distance-Aware Adaptive Settling:
 *   Adjacent slot movement (1 step) generates ~35 pulses (~700 ms).
 *   Full 180-degree return (Slot 6 -> Slot 1, 5 steps) dynamically scales
 *   to ~62 pulses (~1240 ms) so the turntable completely stops and settles
 *   before the camera captures, completely eliminating motion blur.
 */

#include <Adafruit_NeoPixel.h>

// Check for Arduino UNO Q Bridge header
#if defined(ARDUINO_ARCH_ZEPHYR) || defined(ARDUINO_UNO_Q) ||                  \
    __has_include(<Arduino_RouterBridge.h>)
#include <Arduino_RouterBridge.h>
#define HAS_ROUTER_BRIDGE 1
#endif

const int SERVO_PIN = 9;
const int LED_PIN = 8;

Adafruit_NeoPixel led(1, LED_PIN, NEO_GRB + NEO_KHZ800);

// Servo pulse widths for 6 slot positions (in microseconds)
const int POSITIONS[6] = {480, 940, 1360, 1780, 2220, 2650};

// Non-blocking pulse state machine
int currentSlot = 1;
volatile int targetPulse = 500;
volatile int pulsesRemaining = 0;
unsigned long lastPulseTime = 0;

void setOrange() {
  led.setPixelColor(0, led.Color(255, 120, 0));
  led.show();
}

void setGreen() {
  led.setPixelColor(0, led.Color(0, 255, 0));
  led.show();
}

void setRed() {
  led.setPixelColor(0, led.Color(255, 0, 0));
  led.show();
}

void setAmber() {
  led.setPixelColor(0, led.Color(160, 90, 0));
  led.show();
}

void setOff() {
  led.setPixelColor(0, led.Color(0, 0, 0));
  led.show();
}

// Non-blocking trigger: safe to call from Bridge RPC callbacks (< 1
// microsecond)
void moveServoSlot(int slot) {
  if (slot >= 1 && slot <= 6) {
    int dist = abs(slot - currentSlot);
    currentSlot = slot;
    targetPulse = POSITIONS[slot - 1];
    // Dynamic settle pulses (50 Hz = 20ms per pulse):
    // 1-step move (36 deg): 45 pulses (~900 ms)
    // 5-step return (Slot 6 -> 1, 180 deg sweep): 102 pulses (~2040 ms = 2.04s)
    if (dist <= 1) {
      pulsesRemaining = 45;
    } else {
      pulsesRemaining = 45 + (dist - 1) * 15;
    }
  }
}

void setLedState(String col) {
  col.toUpperCase();
  if (col == "PASS" || col == "P" || col == "GREEN") {
    setGreen();
  } else if (col == "FAIL" || col == "F" || col == "RED") {
    setRed();
  } else if (col == "ORANGE" || col == "O") {
    setOrange();
  } else {
    setAmber();
  }
}

void setup() {
  pinMode(SERVO_PIN, OUTPUT);
  digitalWrite(SERVO_PIN, LOW);

  led.begin();
  led.setBrightness(240);
  setAmber();

  // Move to initial home position (Slot 1)
  moveServoSlot(1);
  setGreen();

#if defined(HAS_ROUTER_BRIDGE)
  // Initialize internal Bridge RPC for Arduino UNO Q
  Bridge.begin();
  Bridge.provide_safe("move_servo", moveServoSlot);
  Bridge.provide_safe("set_led", setLedState);
#endif

  // Also initialize Serial for external serial/UART monitoring (D0/D1)
  Serial.begin(115200);
  Serial.println("OK:READY");
}

void loop() {
  unsigned long now = micros();

  // Generate 50Hz PWM pulses non-blockingly (every 20,000 microseconds)
  if (pulsesRemaining > 0 && (now - lastPulseTime >= 20000)) {
    lastPulseTime = now;
    digitalWrite(SERVO_PIN, HIGH);
    delayMicroseconds(targetPulse);
    digitalWrite(SERVO_PIN, LOW);
    pulsesRemaining--;
    // Send completion notification ONLY when motor has completely finished all
    // pulses!
    if (pulsesRemaining == 0) {
      Serial.print("OK:MOVED:");
      Serial.println(currentSlot);
    }
  }

  // Also service standard Serial commands ('1'..'6', 'P', 'F', 'O', 'E', '?')
  if (Serial.available() > 0) {
    char input = Serial.read();

    if (input == '\n' || input == '\r' || input == ' ') {
      return;
    }

    if (input >= '1' && input <= '6') {
      moveServoSlot(input - '0');
      Serial.print("ACK:MOVE:");
      Serial.println(input);
    } else if (input == 'P' || input == 'p') {
      setGreen();
      Serial.println("OK:PASS");
    } else if (input == 'F' || input == 'f') {
      setRed();
      Serial.println("OK:FAIL");
    } else if (input == 'O' || input == 'o') {
      setOrange();
      Serial.println("OK:ORANGE");
    } else if (input == 'E' || input == 'e') {
      setAmber();
      Serial.println("OK:EMPTY");
    } else if (input == '?') {
      Serial.println("OK:READY");
    } else {
      Serial.print("ERR:UNKNOWN_CMD:");
      Serial.println(input);
    }
  }
}

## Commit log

2026-10-03 feat: complete Edge AI vision inspection system with models, firmware, and documentation
    [labels_makesense.csv, labels_makesense_classification.csv, results.csv]
2026-10-03 chore(readme): add comprehensive documentation for BMS EIM Vision Inspection system
2026-10-05 feat: add project documentation, CAD files, and dataset images for edge AI vision inspection system
    [Body.stl, Cap.stl, Diffuser.stl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]
